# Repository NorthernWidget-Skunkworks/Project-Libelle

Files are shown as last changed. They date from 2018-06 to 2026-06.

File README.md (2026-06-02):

# Project-Libelle



*Libelle* is a spectrally-resolving shortwave pyranometer that measures solar irradiance across six spectral bands from UV-B through short-wave infrared (~280–1700 nm). The name is German for both "dragonfly" — an organism with up to 30 types of photoreceptors spanning UV to near-IR — and "spirit level," a nod to the onboard accelerometer used to correct measurements for sensor tilt.

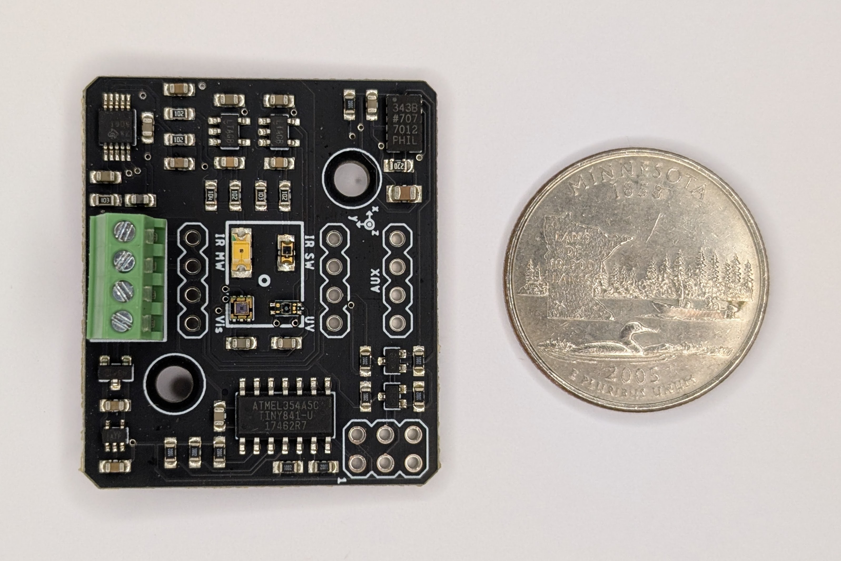
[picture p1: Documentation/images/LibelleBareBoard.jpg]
Libelle bare board next to a US quarter for scale


## Measurements

| Channel | Sensor | Approx. range |
|---|---|---|
| UV-B | VEML6075 | ~280–315 nm |
| UV-A | VEML6075 | ~315–400 nm |
| Visible (ALS) | VEML6030 | ~400–700 nm |
| White (broadband) | VEML6030 | ~300–700 nm |
| Near-IR (short) | VEMD1060X01 | ~700–1100 nm |
| Near-IR (mid) | SD003-151-001 | ~1000–1700 nm |
| Temperature | NTC thermistor | — |
| Tilt (roll + pitch) | ADXL343 | — |

Spectral response curves for each channel are in [`Analysis/SpectrumResponsePlots/`](Analysis/SpectrumResponsePlots/).

## Hardware

The board integrates its sub-sensors through an ATtiny841, which aggregates their readings and presents a single I²C slave interface to the host. The host never addresses the sub-sensors directly.

**Key ICs:** VEML6075 (UV), VEML6030 (visible/lux), VEMD1060X01 + SD003-151-001 (NIR photodiodes), ADS1115 (16-bit ADC), ADXL343 (accelerometer), ATtiny841 (I²C bridge), TPS79733 (3.3 V LDO)

### Net radiation

Two Libelle modules can share a single I²C bus simultaneously — one facing skyward (UP) and one facing down (DOWN) — to compute net shortwave radiation (↓ − ↑). The I²C address is set by solder jumper JP1:

| Orientation | Address |
|---|---|
| Up (default, JP1 open) | `0x40` |
| Down (JP1 bridged) | `0x41` |

## Electrical

- **Supply:** 3.3–5.5 V (onboard 3.3 V LDO, max input 5.5 V; I²C lines are level-shifted to match host supply)
- **Interface:** I²C (slave)
- **Connectors:** 4-pin screw terminal (J1) and 4-pin headers (J2–J4); ISP header for ATtiny firmware updates (ISP1)
- **JP1:** module I²C address select (open → `0x40`; bridged → `0x41`)
- **JP2:** ADXL343 accelerometer I²C address select (open → `0x1D`; bridged → `0x53`); for advanced use only — firmware assumes `0x1D`

### External connector pinout

| Pin | Function |
|-----|---|
| VIN | Supply (3.3–5.5 V) |
| GND | Ground |
| SDA | I²C data |
| SCL | I²C clock |

### Interrupt / auxiliary pins

| Pin | Function |
|-----|---|
| D0 | Lux interrupt (active low) |
| D1 | ADC interrupt (active low) |
| D7 | Address select (pull low → `0x41`) |

## Software

Install the [Libelle Arduino library](https://github.com/NorthernWidget-Skunkworks/Libelle_Library) from the Arduino Library Manager or by cloning the repository.

### Quick start

```cpp
#include <Libelle.h>

Libelle pyroUp(UP);

void setup() {
    Serial.begin(38400);
    pyroUp.begin();
    Serial.println(pyroUp.getHeader());
}

void loop() {
    Serial.println(pyroUp.getString());
    delay(1000);
}
```

For a net radiation setup with two modules:

```cpp
Libelle pyroUp(UP);
Libelle pyroDown(DOWN);
```

### Key API methods

| Method | Returns | Description |
|---|---|---|
| `begin()` | `bool` | Initialize; returns `false` if bridge or accelerometer unreachable |
| `getHeader()` | `String` | Comma-separated column names with units |
| `getString()` | `String` | Comma-separated measurement values |
| `getUVA()` | `long` | UV-A raw counts |
| `getUVB()` | `long` | UV-B raw counts |
| `getLux()` | `float` | Illuminance (lux) |
| `getIR_Short()` | `float` | NIR ~700–1100 nm, TIA output voltage (V) |
| `getIR_Mid()` | `float` | NIR ~1000–1700 nm, TIA output voltage (V) |
| `getTemp()` | `float` | Housing temperature (°C) |
| `getRoll()` | `float` | Roll angle (°) |
| `getPitch()` | `float` | Pitch angle (°) |

`getIR_Short()` and `getIR_Mid()` return transimpedance amplifier output voltage, not W/m². Converting to irradiance requires calibration against a reference pyranometer; see the [library documentation](https://github.com/NorthernWidget-Skunkworks/Libelle_Library) for details.

## Register map and firmware internals

The Libelle firmware runs on an ATtiny841 bridge, which exposes an I2C slave register map to the host logger. Default I2C addresses: `0x40` (UP orientation), `0x41` (DOWN orientation). The onboard ADXL343 accelerometer is read directly by the master on the same I2C bus (not bridged through the ATtiny).

Two layouts exist: the **current firmware** (deployed) and the **proposed** layout under [NW-Device-Specification](https://github.com/NorthernWidget/NW-Device-Specification) Schema 1.

### Current register map (deployed firmware)

26-byte array. Status ready flag is bit 7.

```
0x00        CTRL/Status   bit 7=ready; bit 2=auto-range disable;
                          bit 3=manual auto-range trigger; bits 1:0=update rate
0x01        —             unused
0x02–0x05   UVA           int32, compensated VEML6075 counts, little-endian
0x06        —             gap (always 0x00) ← ⚠ BUG: see below
0x07–0x0A   UVB           int32, compensated VEML6075 counts, little-endian
0x0B–0x0C   ALS           uint16, raw VEML6030 counts (visible)
0x0D–0x0E   White         uint16, raw VEML6030 counts
0x0F        —             gap
0x10–0x11   Lux mult      uint16, auto-range gain×integration scaler
0x12        —             gap
0x13–0x14   IR_Mid        uint16, raw ADS1115 counts (×1.25e-4 → V)
0x15–0x16   IR_Short      uint16, raw ADS1115 counts (×1.25e-4 → V)
0x17–0x18   Therm         uint16, raw ADS1115 counts (Steinhart-Hart → °C)
```

### ⚠ Known bug: UVB reads 256× too large

The firmware writes UVB starting at register `0x07`. The library reads UVB starting at `UVB_ADR = 0x06`. This off-by-one causes the library to assemble the UVB int32 as:

```
Byte 0 (LSB): Reg[0x06] = 0x00  ← always zero (gap byte)
Byte 1:       Reg[0x07] = UVB true byte 0
Byte 2:       Reg[0x08] = UVB true byte 1
Byte 3 (MSB): Reg[0x09] = UVB true byte 2  ← true byte 3 (Reg[0x0A]) dropped
```

Result: `getUVB()` returns approximately `true_UVB × 256`. All historical UVB data collected with this firmware and library combination is affected by this systematic error. See [issue #TBD](https://github.com/NorthernWidget/Project-Libelle/issues) for tracking.

### Proposed register map (NW-Device-Specification Schema 1)

Two 32-byte pages. The UVB register mismatch is corrected in this layout.

**Page 0 (0x00–0x1F) — Identity (EEPROM)**

```
Block 0 (0x00–0x07)   Core identity
  0x00        0x01                          Schema (NW-Device-Specification v1)
  0x01–0x07   'L','i','b','e','l','l','e'   Device name (7 bytes, exact fit)

Block 1 (0x08–0x0F)   Version
  0x08        HW major
  0x09        HW minor
  0x0A        FW patch          (NW combined-repo convention)
  0x0B–0x0D   0x00,0x00,0x00    Unused (combined repo)
  0x0E–0x0F   0x00,0x00         Reserved

Block 2 (0x10–0x17)   Serial number
  0x10–0x11   0x4C,0x01         Board type ('L'=0x4C, revision index 1)
  0x12–0x13   [manufacture]     Group ID
  0x14–0x15   [manufacture]     Unique ID
  0x16–0x17   0x00,0x00         FirmwareID (legacy, reserved)

Block 3 (0x18–0x1F)   Integrity + administration
  0x18–0x1C   0x00 ×5           Reserved
  0x1D        0x00              Magic byte (reserved; purpose TBD)
  0x1E        [computed]        CRC-8 of bytes 0x00–0x1D
  0x1F        0x4C or 0x0C      I2C address (0x4C=UP, 0x0C=DOWN; writable)
```

**Page 1 (0x20–0x3F) — Sensor data (SRAM)**

```
Block 0 (0x20–0x27)   VEML6030 — visible light
  0x20        Status       bit 0=ready, bit 1=VEML6075 fault,
                           bit 2=VEML6030 fault, bit 3=ADS1115 fault,
                           bit 7=pan-fault
  0x21        Extended faults (reserved, 0x00)
  0x22–0x23   ALS          uint16, raw VEML6030 counts, little-endian
  0x24–0x25   White        uint16, raw VEML6030 counts, little-endian
  0x26–0x27   Lux mult     uint16, auto-range scaler (ALS × mult × 0.0036 → lux)

Block 1 (0x28–0x2F)   VEML6075 — UV
  0x28–0x2B   UVA          int32, compensated counts, little-endian
  0x2C–0x2F   UVB          int32, compensated counts, little-endian

Block 2 (0x30–0x37)   ADS1115 — IR + temperature
  0x30–0x31   IR Short     uint16, raw ADC counts (×1.25e-4 → V)
  0x32–0x33   IR Mid       uint16, raw ADC counts (×1.25e-4 → V)
  0x34–0x35   Temperature  uint16, raw ADC counts (Steinhart-Hart → °C in library)
  0x36–0x37   Reserved

Block 3 (0x38–0x3F)   ADXL343 — accelerometer (hardware v2 only; see below)
  0x38–0x39   Accel X   int16, little-endian
  0x3A–0x3B   Accel Y   int16, little-endian
  0x3C–0x3D   Accel Z   int16, little-endian
  0x3E–0x3F   Reserved
```

No Page 2. Calibration constants (Steinhart-Hart coefficients, UV cross-talk compensation) are currently hardcoded in the library. If per-unit calibration is added, Page 2 is the natural home. Accelerometer calibration offsets, if needed, would also go in Page 2 following the pattern of the Apis sensor.

**Accelerometer (ADXL343):** In the current hardware (v1), the ADXL343 is wired to the master's I2C bus and read directly by the library at address `0x1D` (UP) or `0x53` (DOWN) — it is not bridged through the ATtiny. This requires the logger to manage two I2C addresses. In hardware v2, the ADXL343 will move to the ATtiny's software I2C bus so all data is accessible through a single address; Block 3 of Page 1 is reserved for this. See [issue #19](https://github.com/NorthernWidget-Skunkworks/Project-Libelle/issues/19).

### Migration notes for Schema 1 update

1. **Status bit:** Current firmware uses bit 7 of `Reg[0x00]` as the ready flag; Schema 1 places the status byte at 0x20 with bit 0 as the ready flag. Both the register address and the bit position must change together.
2. **UVB register offset:** Correct firmware to write UVB at `0x28` (Page 1, Block 1) — eliminates the ×256 error.
3. **Auto-range:** `bit 2` and `bit 3` of CTRL need equivalent representation in Schema 1 status/config byte.

## Mechanical

CNC-millable mounting hardware designs are available on [Easel (Inventables)](https://www.inventables.com/):

- [Pipe mount](https://easel.inventables.com/projects/cAirZefIUws53oghGYYopw) — accepts 1.25"–3.25" ID pipe with 1/4" U-bolts (common US sizes: 1.25", 1.5", 1.75", 2")
- [Drilling jig](https://easel.inventables.com/projects/s-fOn9DWTmkeizO0vO8MGw) — for the Libelle enclosure box

| Pipe mount | Enclosure circle cut |
|---|---|
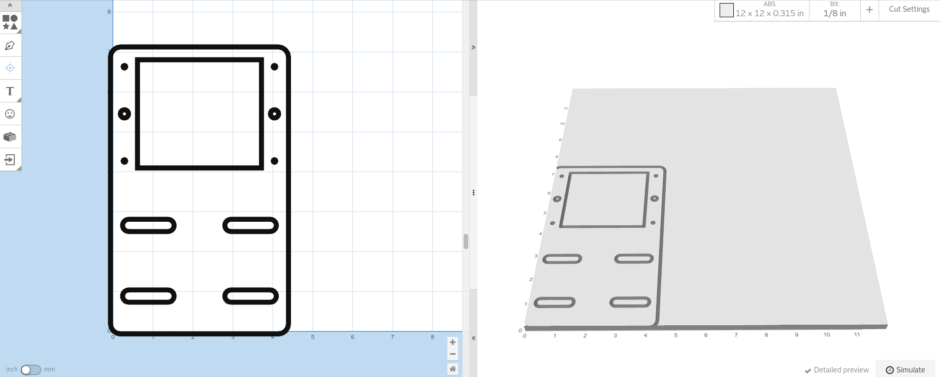
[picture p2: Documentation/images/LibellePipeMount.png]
Pipe mount CNC design
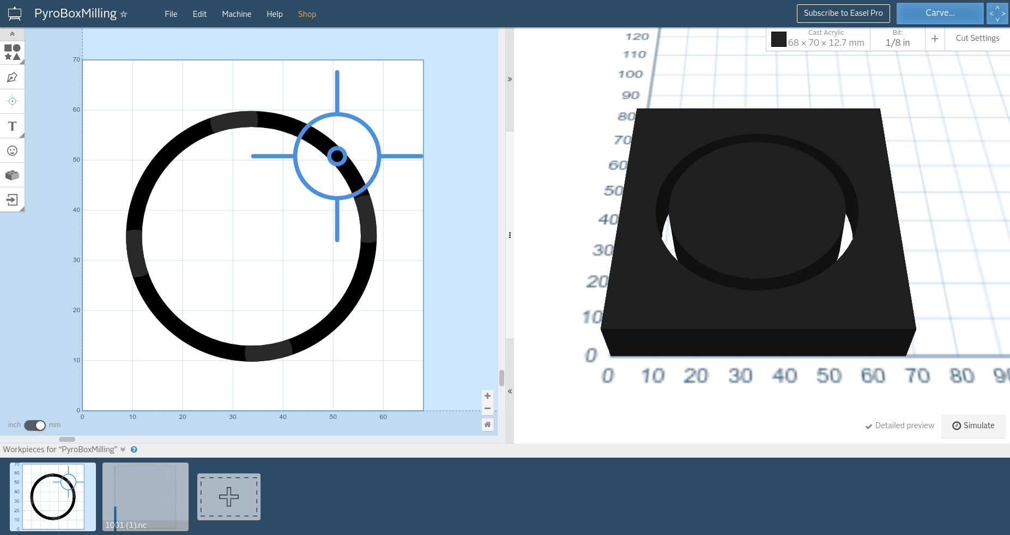
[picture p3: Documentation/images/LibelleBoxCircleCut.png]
Enclosure circle cut CNC design
|  |  |

SolidWorks source files and STLs are in [`Mechanical/`](Mechanical/).

## Related projects

- [Project-Liasis](https://github.com/NorthernWidget-Skunkworks/Project-Liasis) — companion longwave (thermal IR) pyrgeometer
- [Liasis Library](https://github.com/NorthernWidget-Skunkworks/Liasis_Library) — Arduino library for the Liasis pyrgeometer

## NW-Device-Specification — Schema 1, Page 0

Implements [NW-Device-Specification](https://github.com/NorthernWidget/NW-Device-Specification) Schema 1. The 32-byte identity block (Page 0) is stored at the top of EEPROM:

```
Block 0:  Schema=0x01, Name='L','i','b','e','l','l','e'
Block 1:  HW major=[mfr], HW minor=[mfr], FW patch=[mfr], 0x00,0x00,0x00, Reserved
Block 2:  Board type=0x4C01 ('L'=0x4C, rev 1), Group ID=[mfr], Unique ID=[mfr], FirmwareID=0x0000
Block 3:  Reserved, Magic=0x00, CRC=[computed], I2C address=0x4C (UP) / 0x0C (DOWN)
```

Legacy deployed units carry board types `0x2300`/`0x2301` (formerly Dyson SW, Monarch SW).

## License

Hardware:  <a rel="license" href="http://creativecommons.org/licenses/by-sa/4.0/">Creative Commons Attribution-ShareAlike 4.0 International</a>

Firmware: [GNU General Public License v3](LICENSE_for_code)

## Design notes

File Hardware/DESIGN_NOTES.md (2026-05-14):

# Hardware Design Notes

## Power supply: LDO vs. buck converter

The TPS79733 (ultra-low-Iq 3.3 V LDO, <1 µA Iq) was chosen over a synchronous buck converter
(TPS62172, 500 mA, 2.5–7 V input). Two simulation files documenting this exploration were
removed from the repo after this note was written (recoverable from git history):

- `Simulations/slvm434a/` — PSpice transient startup simulation of TPS62172 (OrCAD binary)
- `Simulations/PowerFilter.asc` — LTSpice AC sweep of LC + RC output filter topologies
  (L swept 100 µH–2 mH, R = 27 Ω, C = 44 µF), evaluating whether buck switching noise
  could be adequately filtered for the analog signal chain

The LDO was chosen for two reasons:

1. **Analog noise sensitivity.** The two LTC2054 TIA op-amps driving the IR photodiodes are
   extremely sensitive to supply noise. Buck-converter switching ripple (and its harmonics)
   would couple directly into the transimpedance measurement. The PowerFilter simulations
   represent the investigation into whether filtering could solve this; the complexity and
   board area of a multi-stage LC filter were apparently not worth it compared to simply
   using an LDO.

2. **Low load current.** Total board current is well below 50 mA (ATtiny841 + VEML6075 +
   VEML6030 + ADS1115 + ADXL343 + 2× LTC2054). The efficiency loss of an LDO at this
   current level (≤85 mW dissipation from a 5 V supply) is negligible for a solar radiation
   sensor, which is not battery-constrained.

Even with the clean LDO supply, R3 (27 Ω) in the SmallBoard design forms an RC filter
between the digital 3V3 rail and the ADXL343's VS analog supply pin, providing an extra
layer of decoupling for the accelerometer's analog domain.

## Transimpedance amplifier for NIR photodiodes

`Simulations/PhotodiodeAmp.asc` and `Simulations/PhotodiodeAmp_Photoelectric.asc` simulate
the LTC2054 TIA circuit used for the IR photodiode channels (VEMD1060X01 and SD003-151-001).

- `PhotodiodeAmp.asc` — DC sweep of photodiode current (–1.59 µA), 1 MΩ feedback, 2 µF
  feedback capacitor, 100-run Monte Carlo for component tolerance analysis.
- `PhotodiodeAmp_Photoelectric.asc` — Full photodiode model (Cj = 10 pF, Rsh = 2 GΩ,
  Rs = 1 µΩ), transient analysis, Monte Carlo. R1 = 1 kΩ, R2 = 1 MΩ, R3 = 2 kΩ,
  C1 = 0.15 µF, C2 = 0.01 µF.

The 1 MΩ feedback resistor sets the transimpedance gain; output is a voltage proportional
to photodiode current, reported as volts (not W/m²). Irradiance calibration requires
comparison against a reference pyranometer.

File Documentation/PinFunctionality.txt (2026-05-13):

Pin Functionality Libelle Short-Wave

Pin		Function
D0		Lux Int, Active Low
D1		Adc Int, Active Low
D7		Slave Address Select 
D3		Software SCL
D2		Software SDA

Function Explanation:

Lux Int:
Lux sensor (VEML6030) can be configured to output an interrupt for certian situations, this pin is native high (pull up), and it pulled low by the Lux sensor if an interrupt is triggered. Interrupt trigger must be configured by user.

Adc Int:				
ADC (ADS1115) can be configured to output an interrupt for certian situations, this pin is native high (pull up), and it pulled low by the ADC sensor if an interrupt is triggered (generally used to indicate a finished conversion). Interrupt trigger must be configured by user.

Slave Address Select:
This pin is used to select I2C device (if the device is the "top" or "bottom" device). This pin must be pulled up internally, and is natively floating (can be pulled up internally). This pin is an input, when the solder jumper on the board (J1) is jumped, this pin is pulled low, indicating the alternate device address should be used.

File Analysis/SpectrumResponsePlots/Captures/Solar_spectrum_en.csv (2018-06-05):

x | Curve1
204.85 | 0.1295
216.07 | 0.18429
225.9 | 0.23908
234.31 | 0.29387
242.73 | 0.34866
249.75 | 0.40574
255.36 | 0.46053
262.38 | 0.51761
269.39 | 0.5724
276.41 | 0.62948
282.02 | 0.68655
287.63 | 0.74135
294.65 | 0.79842
300.26 | 0.85322
307.27 | 0.91029
312.89 | 0.96737
319.9 | 1.02216
325.51 | 1.07924
332.53 | 1.13403
339.54 | 1.19111
346.56 | 1.2459
353.57 | 1.30298
360.59 | 1.35777
369.01 | 1.41256
377.43 | 1.46964
387.25 | 1.52443
398.47 | 1.5952
402.68 | 1.62716
412.5 | 1.64998
426.53 | 1.7002
439.16 | 1.73215
458.8 | 1.77779
486.87 | 1.80973
519.14 | 1.80741
531.76 | 1.79597
558.42 | 1.76169
582.27 | 1.71828
603.32 | 1.67258
622.96 | 1.62689
660.85 | 1.53095
679.09 | 1.48297
712.76 | 1.3916
731 | 1.34363
747.84 | 1.29565
766.08 | 1.24768
784.32 | 1.19971
798.38 | 1.16441
815.62 | 1.11836
836.39 | 1.07159
852.74 | 1.02698
870.86 | 0.99171
888.14 | 0.9507
910.59 | 0.90728
933.04 | 0.86159
955.49 | 0.81818
979.34 | 0.77705
996.18 | 0.74735
1020.03 | 0.70622
1045.29 | 0.66737
1071.94 | 0.62852
1097.2 | 0.59195
1111.23 | 0.57367
1137.89 | 0.53939
1167.35 | 0.5051
1196.82 | 0.47538
1226.28 | 0.44566
1255.75 | 0.41594
1288.02 | 0.39079
1318.88 | 0.36335
1351.15 | 0.34048
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

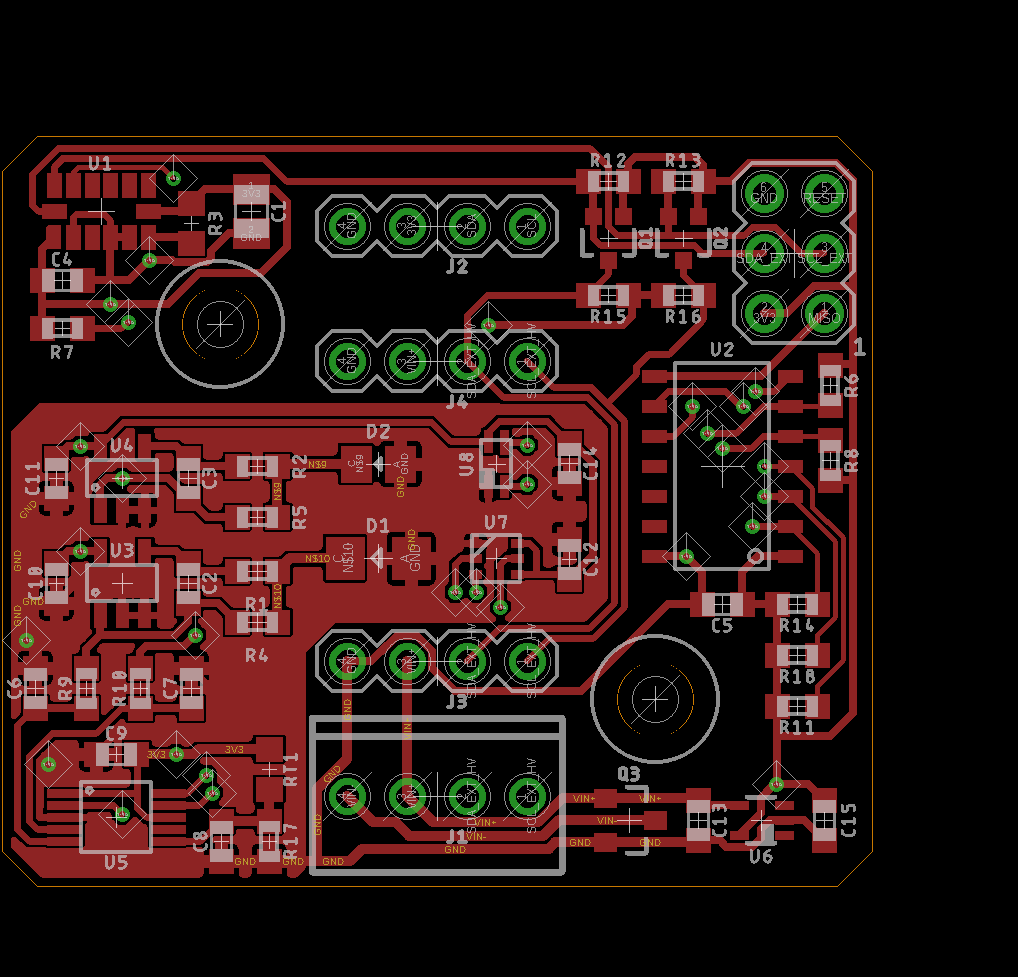
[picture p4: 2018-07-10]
Hardware/Libelle_RefDesignators.png

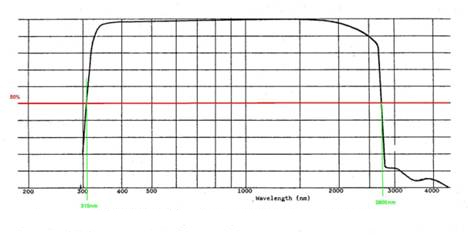
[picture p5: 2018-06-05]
Analysis/SpectrumResponsePlots/Captures/Spectral_Range_KippZonen.jpg

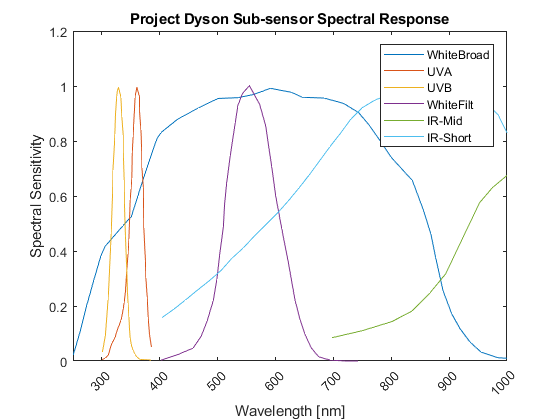
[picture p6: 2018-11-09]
Analysis/SpectrumResponsePlots/PAR_Spectrum.png

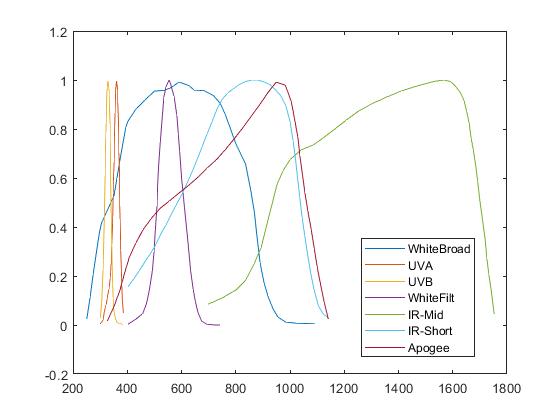
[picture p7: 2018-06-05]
Analysis/SpectrumResponsePlots/Spectrum.jpg

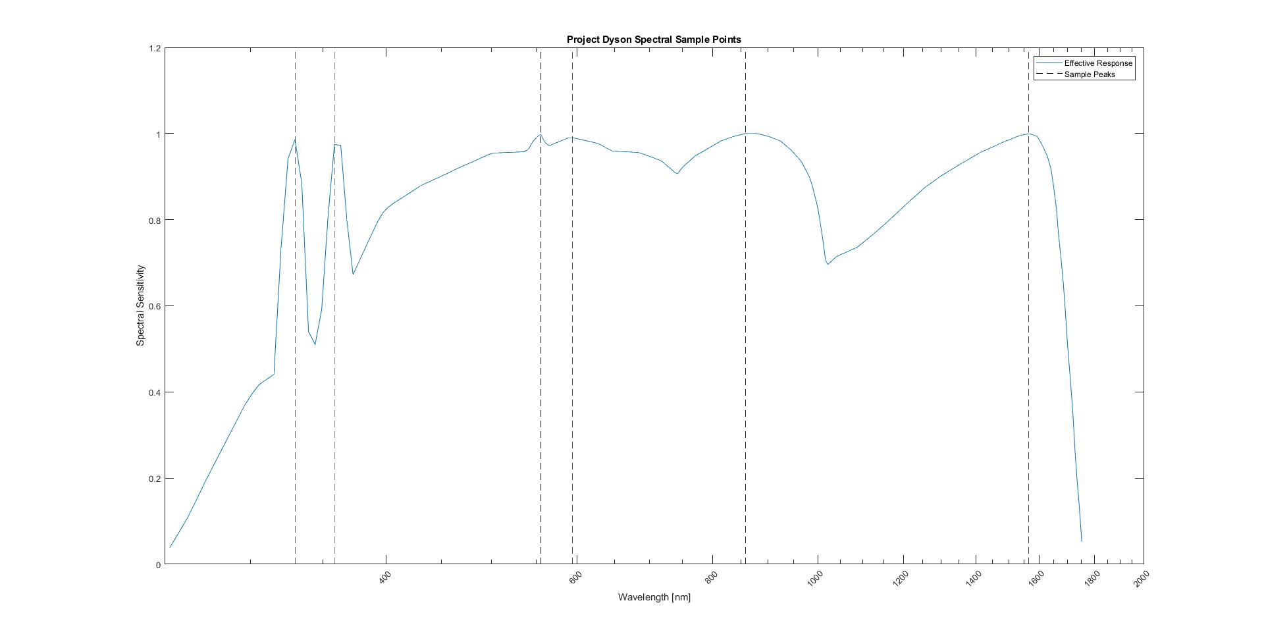
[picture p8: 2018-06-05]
Analysis/SpectrumResponsePlots/Libelle_SamplePeaks.jpg

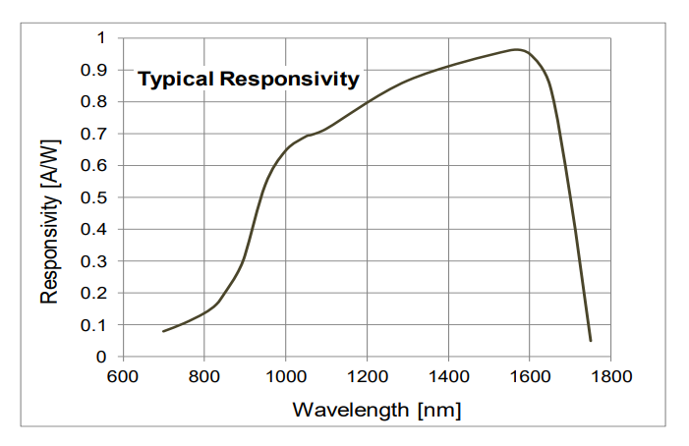
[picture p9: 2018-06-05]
Analysis/SpectrumResponsePlots/Captures/IR_MidWave_Response.png

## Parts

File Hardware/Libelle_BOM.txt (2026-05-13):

Partlist exported from C:/Users/You/Documents/Project-Libelle/Hardware/ShortWaveModule_SmallBoard.sch at 7/9/2018 9:44 AM

Qty Value                   Device                  Package              Parts                                         Description                                                                          DIGIKEY                DISP    MF                  MPN                PROD_ID     VALUE   VALUE_PART
2                           MOUNTING_HOLE4_NP       4_40                 H1, H2                                        Genaric Mechanical Mounting Hole                                                                                                                                                         
2   0.15uF                  C-EU0.15UFC0603         C0603                C2, C3                                        CAPACITOR, European symbol                                                           732-7990-1-ND                  Wurth               885012206072                                     
8   0.1uF                   C-EU0.1UFC0603          C0603                C4, C5, C8, C9, C10, C11, C12, C14            CAPACITOR, European symbol                                                           490-6051-1-ND                  Murata              GCM188R71E104KA57D                               
1   100k                    R-EU_P100KR0603         R0603                R4                                            RESISTOR, European symbol                                                            P100KDBCT-ND                   Panasonic           ERA-3AEB104V                           100k      
10  10k                     R-EU_10KR0603           R0603                R6, R7, R8, R11, R12, R13, R14, R15, R16, R18 RESISTOR, European symbol                                                            P10.0KHCT-ND                   Panasonic           ERJ-3EKF1002V                          10k       
1   10k                     R-EU_P10KR0603          R0603                R17                                           RESISTOR, European symbol                                                            P10KDBCT-ND                    Panasonic           ERA-3AEB103V                           10k       
1   10k                     R-EU_P10KR0603          R0603                R5                                            RESISTOR, European symbol                                                            P10KDBCT-ND                    Panasonic           ERA-3AEB103V                           10k       
1   10k                     THERMISTOR10K           R0603                RT1                                           Thermistor                                                                           490-16279-1-ND                 Murata              NCU18XH103F60RB                                  
1   10uF                    C-EU10UFC0805           C0805                C1                                            CAPACITOR, European symbol                                                           490-6473-6-ND                  Murata              GRM21BR61C106KE15K                               
4   1k                      R-EU_P1KR0603           R0603                R1, R2, R9, R10                               RESISTOR, European symbol                                                            P1.0KDBCT-ND                   Panasonic           ERA-3AEB102V                           1k        
4   1uF                     C-EU1UFC0603            C0603                C6, C7, C13, C15                              CAPACITOR, European symbol                                                           1276-6524-1-ND                 Samsung             1276-6524-1-ND                                   
1   27R                     R-EU_27R0603            R0603                R3                                            RESISTOR, European symbol                                                            311-27.0HRCT-ND                Yageo               RC0603FR-0727RL                        27        
2   2N7002                  MOSFET-NCH-2N7002PW     SOT323               Q1, Q2                                        N-channel MOSFETs                                                                    2N7002W-FDICT-ND               Diodes Incorporated 2N7002W-7-F        TRANS-11151 2N7002            
1   ADS1115                 ADS1115                 VSSOP_10             U5                                            ADS1115 - Sigma Delta ADC                                                            296-38849-1-ND                 TI                  ADS1115IDGSR                                     
1   ADXL343                 ADXL343                 LGA-14               U1                                            ADXL343 - Digital Accelerometer(I2C/SPI)                                             ADXL343BCCZ-ND                 Analog Devices      ADXL343BCCZ                                      
1   ATTINY441/841841        ATTINY441/841841        SOIC_14              U2                                            ATTINY441, ATTINY841 8 bit MCU, 4/8k flash, 256/512B SRAM                            ATTINY841-SSU-ND               Atmel               ATTINY841-SSU                                    
1   AVRISP-6                AVRISP-6                AVRISP               ISP1                                          AVR ISP HEADER                                                                                                                                                                           
3   CONN_42.54              CONN_42.54              1X04                 J2, J3, J4                                    Genaric 4 pin connector                                                                                                                                                                  
1   CONN_42.54_SCREW        CONN_42.54_SCREW        1X04_SCREW           J1                                            Genaric 4 pin connector                                                              ED10563-ND                     On Shore            OSTVN04A150                                      
1   DMG3404                 MOSFET-NCH-DMG3404L     SOT23-3              Q3                                            N-channel MOSFETs                                                                    DMG3404L-7DICT-ND              Diodes Incorporated DMG3404L-7                     DMG3404           
2   JUMPER-SMT_2_NO_SILK    JUMPER-SMT_2_NO_SILK    SMT-JUMPER_2_NO_SILK JP1, JP2                                      Normally open jumper                                                                                                                                                                     
2   LTC2054                 LTC2054                 SOT23-5              U3, U4                                        LTC2054 -Single Micropower Zero Drift Op-Amp                                         LTC2054HS5#TRMPBFCT-ND LTC2054 LT                  LTC2054HS5#TRMPBF                                
1   PHOTODIODESD003-151-001 PHOTODIODESD003-151-001 D1206                D1                                            Photodiode                                                                           SD003-151-001CT-ND             Luna Opto           SD003-151-001                                    
1   PHOTODIODEVEMD1060      PHOTODIODEVEMD1060      D0805                D2                                            Photodiode                                                                           VEMD1060X01CT-ND               Vishay              VEMD1060X01                                      
1   TPS79733                TPS79733                DCK_R-PDSO-G5        U6                                            TPS797xx, Ultra low power linear voltage regulator, fixed voltages of 1.8v, 3v, 3.3v 296-11990-1-ND                 TI                  TPS79733DCKR                                     
1   VEML6030                VEML6030                VEML6030             U7                                            VEML6030 - Ambient Light Sensor with I2C Interface                                   VEML6030-GS15CT-ND             Vishay              VEML6030-GS15                                    
1   VEML6075                VEML6075                VEML6075             U8                                            VEML6075 - UVA and UVB Light Sensor with I2C Interface                               VEML6075CT-ND                  Vishay              VEML6075

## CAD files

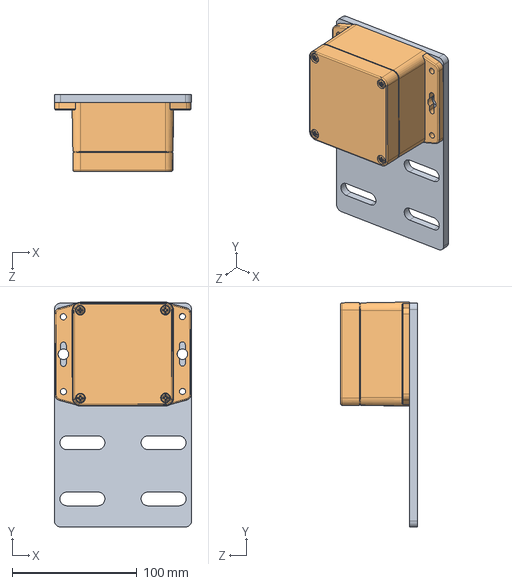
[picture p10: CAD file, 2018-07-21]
Mechanical/PipeMount.SLDASM
110.0 x 180.3 x 61.5 mm
PipeMount
W_-31F1

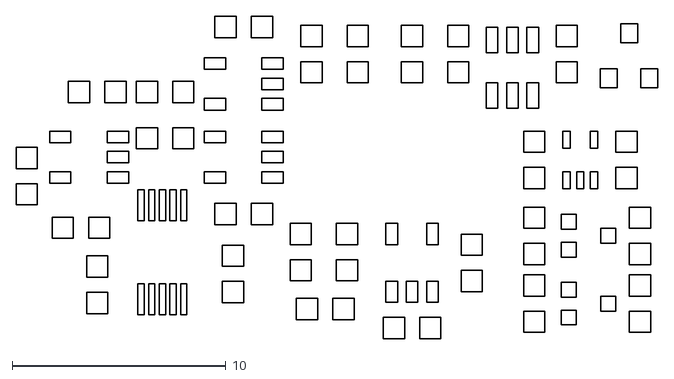
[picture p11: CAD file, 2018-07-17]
Hardware/Stencil.dxf
30.0 x 15.1

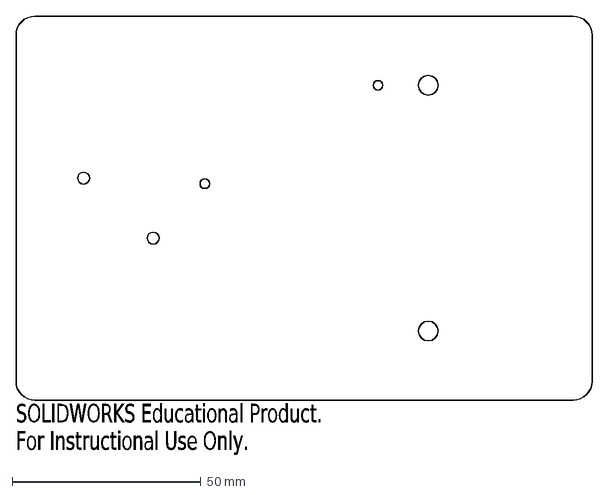
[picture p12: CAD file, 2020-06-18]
Mechanical/CNC/TestWith_KippZonen/PyroTestingPlate.DXF
SOLIDWORKS Educational Product.
For Instructional Use Only.

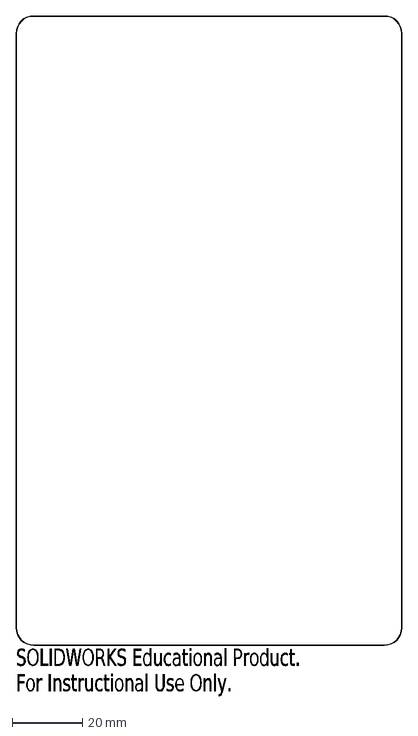
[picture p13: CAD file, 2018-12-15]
Mechanical/PipeMount_Outline.DXF
SOLIDWORKS Educational Product.
For Instructional Use Only.

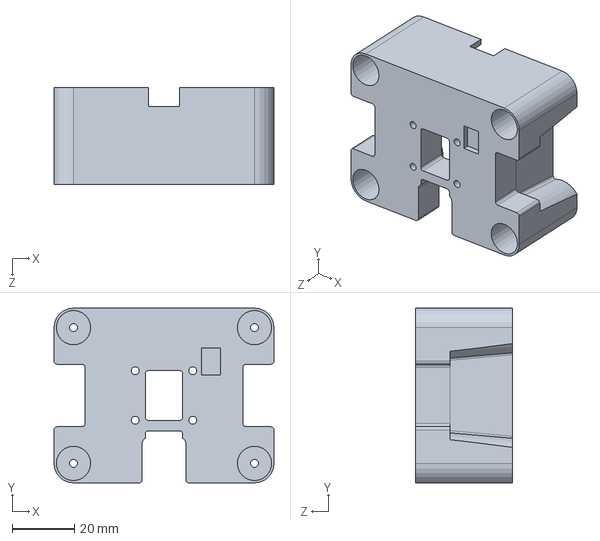
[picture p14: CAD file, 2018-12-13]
Mechanical/BoardCaseMount_DesicantHolders.SLDPRT
70.5 x 56.0 x 31.0 mm

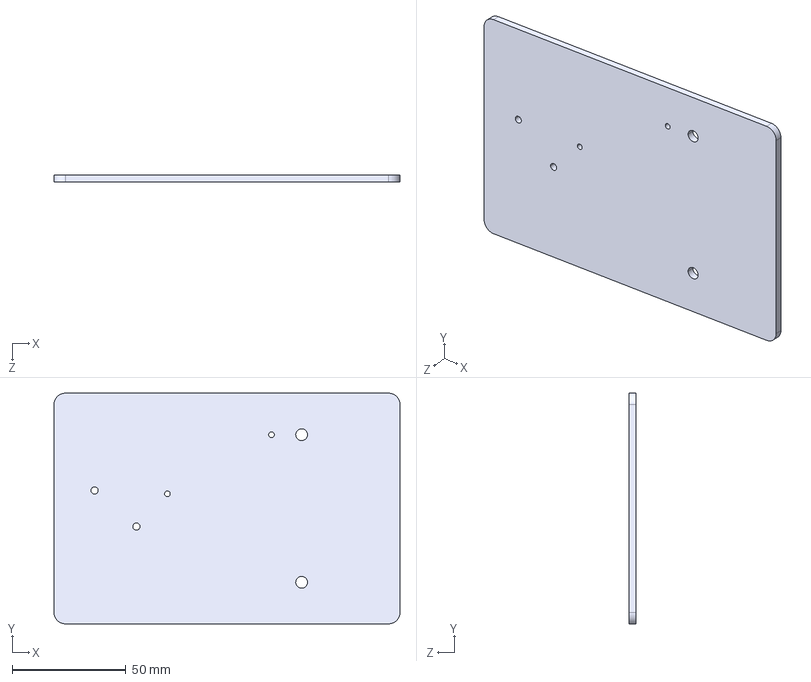
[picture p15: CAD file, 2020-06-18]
Mechanical/CNC/TestWith_KippZonen/PyroTestingBoard.STEP
152.4 x 101.6 x 3.17 mm

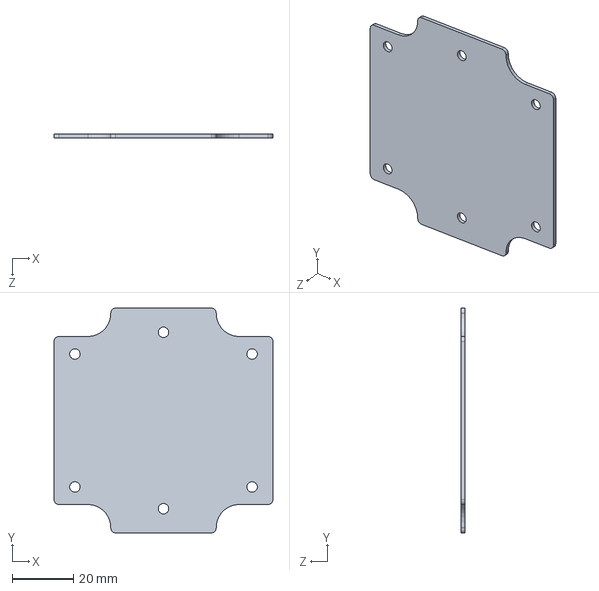
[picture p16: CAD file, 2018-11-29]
Mechanical/WP-31_InternalMountPlate.SLDPRT
71.7 x 73.6 x 1.20 mm

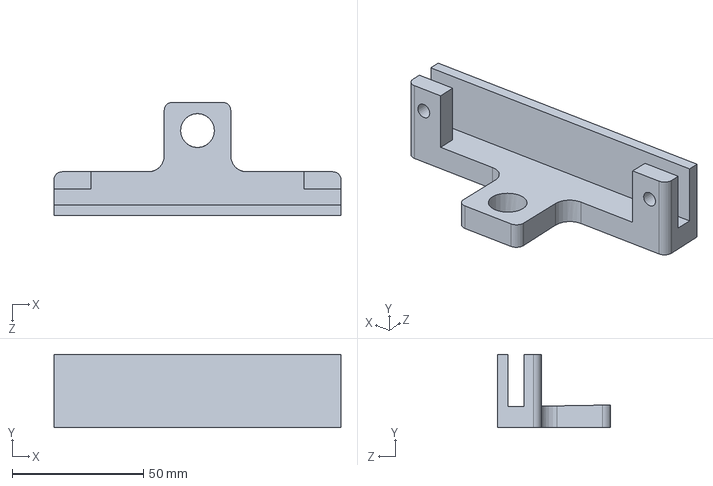
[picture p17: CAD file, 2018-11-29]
Mechanical/DrillGuide.SLDPRT
109.4 x 28.0 x 43.1 mm

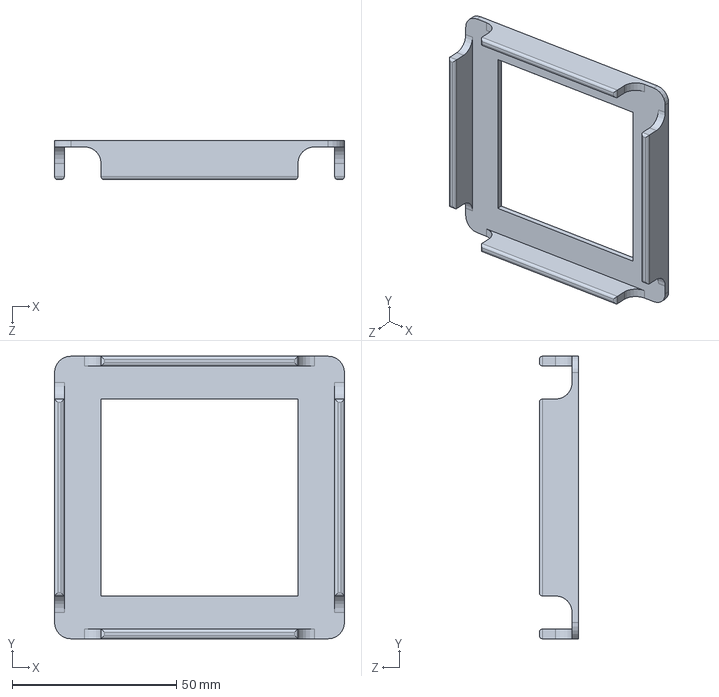
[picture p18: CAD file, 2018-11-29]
Mechanical/DiffuserGuide_TOP.SLDPRT
88.4 x 86.1 x 12.0 mm

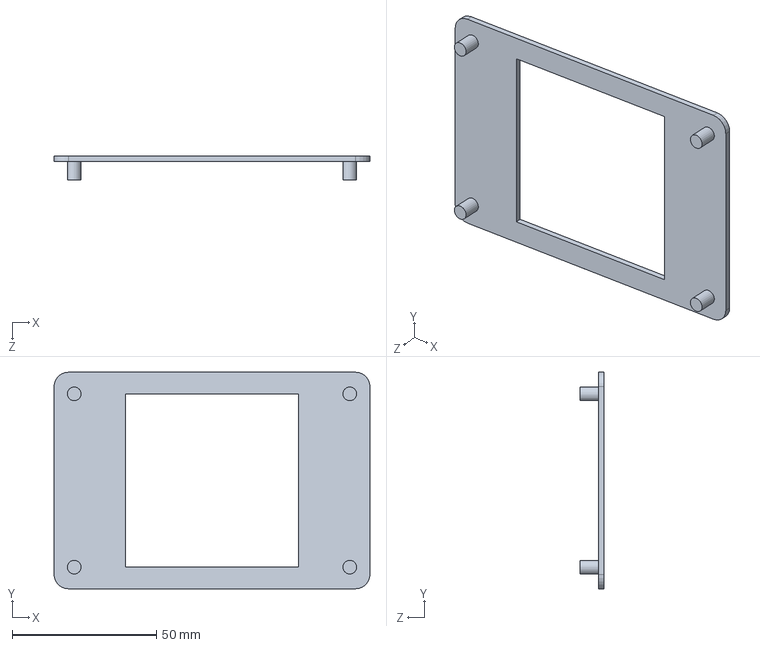
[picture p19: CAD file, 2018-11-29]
Mechanical/DiffuserGuide_BOTTOM.SLDPRT
109.4 x 75.0 x 8.35 mm

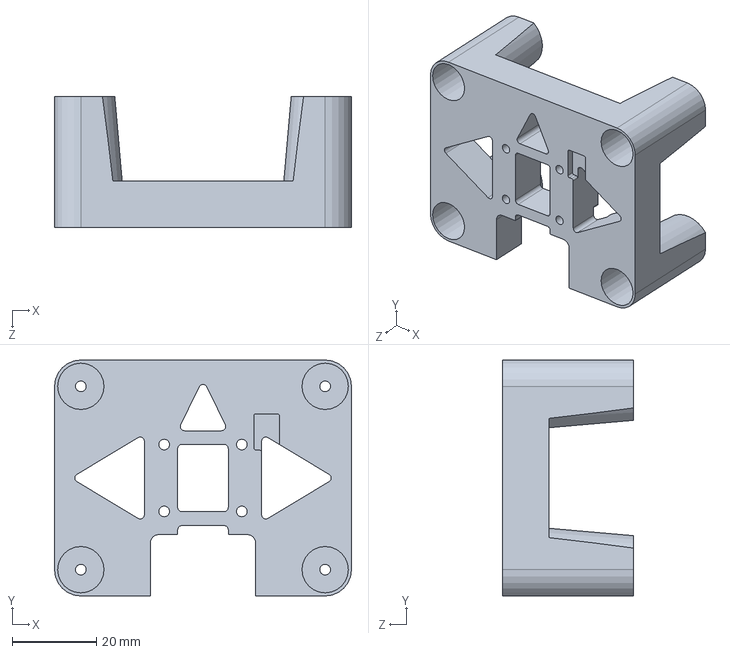
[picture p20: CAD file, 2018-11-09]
Mechanical/BoardCaseMount.SLDPRT
70.5 x 56.0 x 31.0 mm

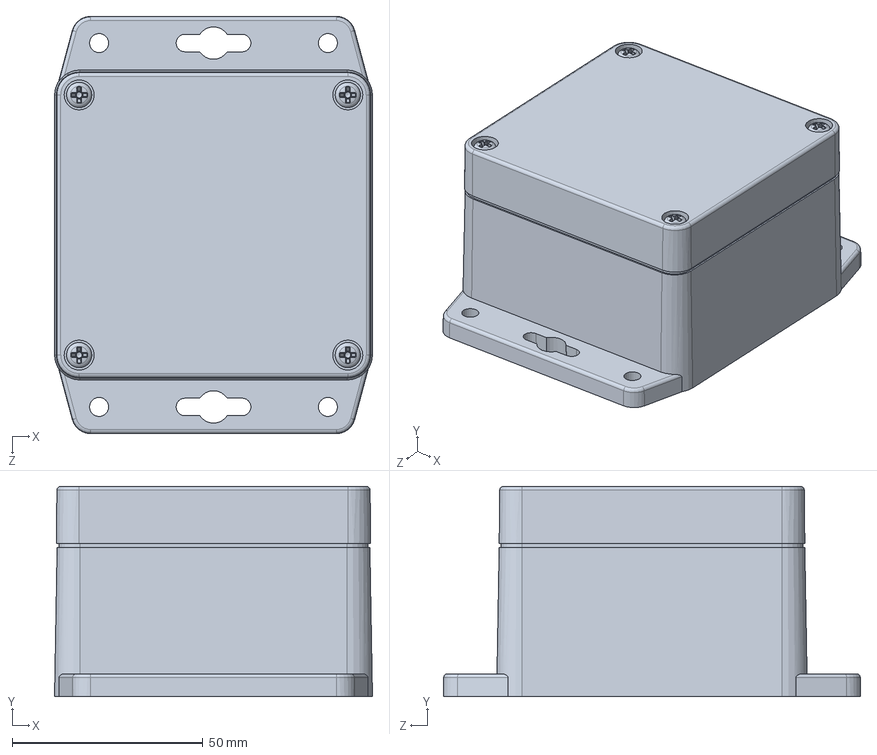
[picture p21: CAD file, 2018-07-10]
Mechanical/W_-31F1.SLDPRT
83.4 x 55.1 x 109.4 mm

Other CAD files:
Mechanical/BoardCaseMount.STL
Mechanical/BoardCaseMount_DesicantHolders.STL
Mechanical/CNC/TestWith_KippZonen/PyroTestingBoard.SLDPRT
Mechanical/CNC/TestWith_KippZonen/PyroTestingBoard.STL
Mechanical/DiffuserGuide_BOTTOM.STL
Mechanical/DiffuserGuide_TOP.STL
Mechanical/DrillGuide.STL
Mechanical/PipeMount.DXF
Mechanical/PipeMount.SLDPRT

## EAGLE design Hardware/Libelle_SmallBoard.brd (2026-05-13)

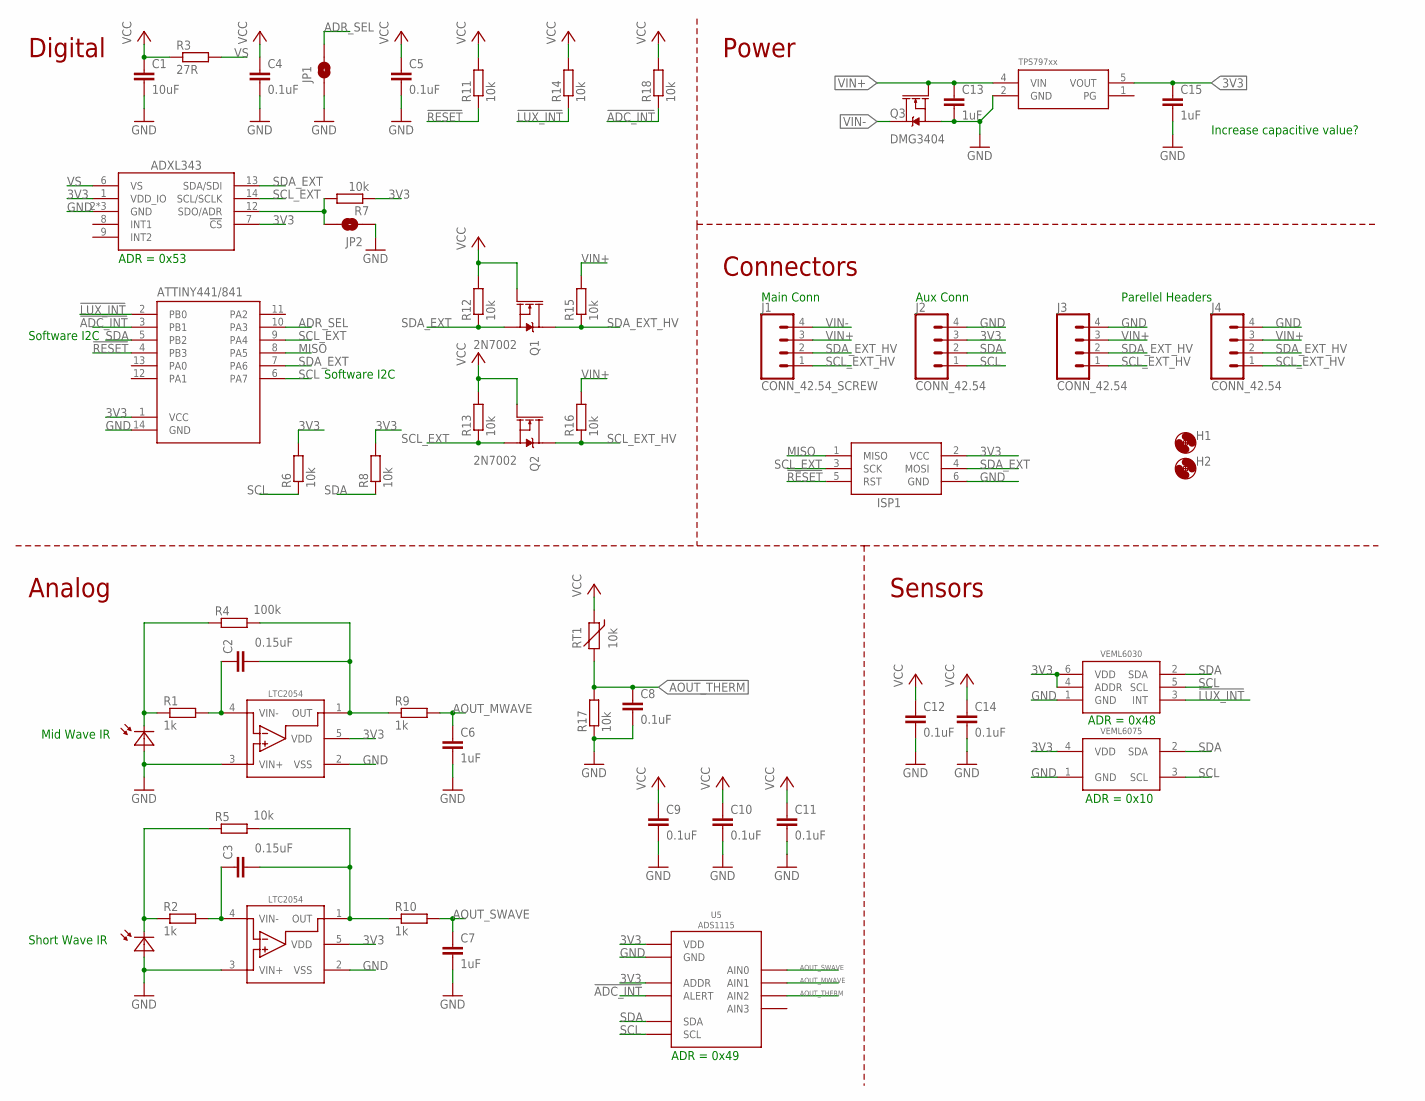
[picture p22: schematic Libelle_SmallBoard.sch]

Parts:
C1: 10uF; C0805
C2, C3: 0.15uF; C0603
C4, C5, C8, C9, C10, C11, C12, C14: 0.1uF; C0603
C6, C7, C13, C15: 1uF; C0603
D1: PHOTODIODESD003-151-001; D1206
D2: PHOTODIODEVEMD1060; D0805
H1, H2: MOUNTING_HOLE4_NP; 4_40
ISP1: AVRISP-6; AVRISP
J1: CONN_42.54_SCREW; 1X04_SCREW
J2, J3, J4: CONN_42.54; 1X04
JP1, JP2: JUMPER-SMT_2_NO_SILK; SMT-JUMPER_2_NO_SILK
Q1, Q2: 2N7002; SOT323
Q3: DMG3404; SOT23-3
R1, R2, R9, R10: 1k; R0603
R3: 27R; R0603
R4: 100k; R0603
R5, R6, R7, R8, R11, R12, R13, R14, R15, R16, R18: 10k; R0603
R17: 10k; R0603; MPN ERA-3AEB103V; DIGIKEY P10KDBCT-ND
RT1: 10k; R0603
U1: ADXL343; LGA-14
U2: ATTINY441/841841; SOIC_14
U3, U4: LTC2054; SOT23-5
U5: ADS1115; VSSOP_10
U6: TPS79733; DCK_R-PDSO-G5
U7: VEML6030
U8: VEML6075

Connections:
3V3: C1.1, C4.1, C5.1, C9.1, C10.1, C11.1, C12.1, C14.1, C15.1, ISP1.2 (VCC), J2.3, Q1.1 (G), Q2.1 (G), R3.1, R6.2, R7.1, R8.2, R11.2, R12.2, R13.2, R14.2, R18.2, RT1.1 (2), U1.1 (VDD_IO), U1.7 (!CS), U2.1 (VCC), U3.5 (VDD), U4.5 (VDD), U5.1 (ADDR), U5.8 (VDD), U6.5 (VOUT), U7.4 (ADDR), U7.6 (VDD), U8.4 (VDD)
!ADC_INT: R18.1, U2.3 (PB1), U5.2 (ALERT)
!LUX_INT: R14.1, U2.2 (PB0), U7.3 (INT)
!RESET: ISP1.5 (RST), R11.1, U2.4 (PB3)
ADR_SEL: JP1.2, U2.10 (PA3)
AOUT_MWAVE: C6.1, R9.2, U5.5 (AIN1)
AOUT_SWAVE: C7.1, R10.2, U5.4 (AIN0)
AOUT_THERM: C8.1, R17.2, RT1.2 (1), U5.6 (AIN2)
GND: C1.2, C4.2, C5.2, C6.2, C7.2, C8.2, C9.2, C10.2, C11.2, C12.2, C13.2, C14.2, C15.2, D1.A, D2.A, ISP1.6 (GND), J2.4, J3.4, J4.4, JP1.1, JP2.1, Q3.2 (S), R17.1, U1.2 (GND), U1.4 (GND), U1.5 (GND), U2.14 (GND), U3.2 (VSS), U3.3 (VIN+), U4.2 (VSS), U4.3 (VIN+), U5.3 (GND), U6.2 (GND), U7.1 (GND), U8.1 (GND)
MISO: ISP1.1 (MISO), U2.8 (PA5)
unnamed: JP2.2, R7.2, U1.12 (SDO/ADR)
unnamed: C3.1, R2.2, U4.4 (VIN-)
unnamed: D2.C, R2.1, R5.1
unnamed: D1.C, R1.1, R4.1
unnamed: C2.1, R1.2, U3.4 (VIN-)
unnamed: C2.2, R4.2, R9.1, U3.1 (OUT)
unnamed: C3.2, R5.2, R10.1, U4.1 (OUT)
SCL: J2.1, R6.1, U2.6 (PA7), U5.10 (SCL), U7.5 (SCL), U8.3 (SCL)
SCL_EXT: ISP1.3 (SCK), Q2.2 (S), R13.1, U1.14 (SCL/SCLK), U2.9 (PA4)
SCL_EXT_HV: J1.1, J3.1, J4.1, Q2.3 (D), R16.1
SDA: J2.2, R8.1, U2.5 (PB2), U5.9 (SDA), U7.2 (SDA), U8.2 (SDA)
SDA_EXT: ISP1.4 (MOSI), Q1.2 (S), R12.1, U1.13 (SDA/SDI), U2.7 (PA6)
SDA_EXT_HV: J1.2, J3.2, J4.2, Q1.3 (D), R15.1
VIN+: C13.1, J1.3, J3.3, J4.3, Q3.1 (G), R15.2, R16.2, U6.4 (VIN)
VIN-: J1.4, Q3.3 (D)
VS: R3.2, U1.6 (VS)

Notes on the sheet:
Software I2C
ADR = 0x48
ADR = 0x10
ADR = 0x49
Increase capacitive value?
Digital
Sensors
Power
Analog
Short Wave IR
Mid Wave IR
Connectors
Main Conn
Aux Conn
Parellel Headers
ADR = 0x53

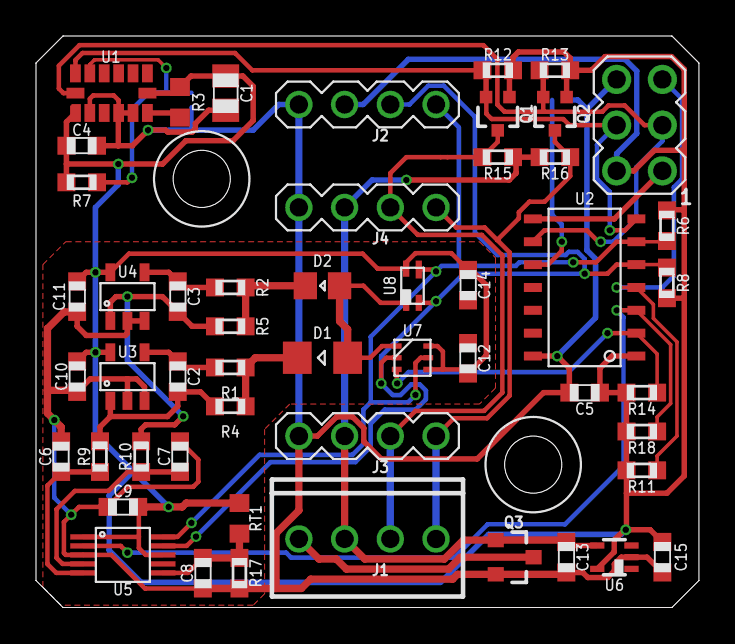
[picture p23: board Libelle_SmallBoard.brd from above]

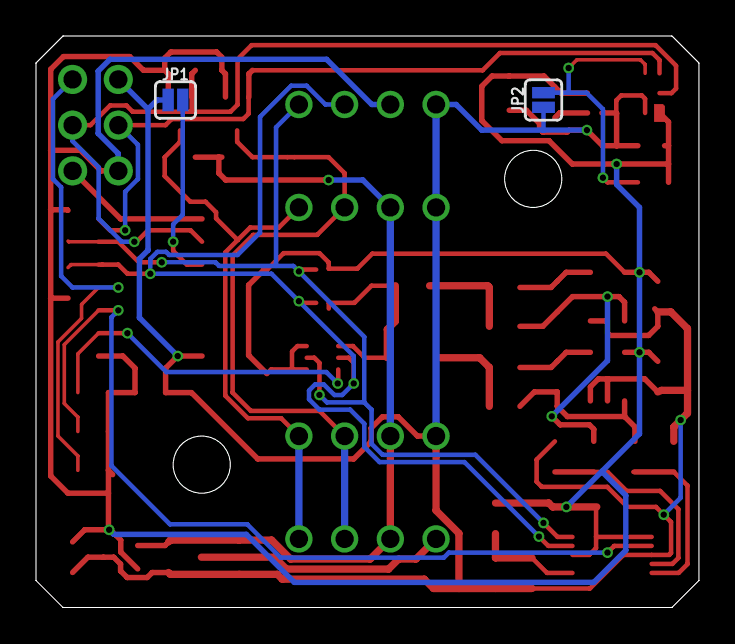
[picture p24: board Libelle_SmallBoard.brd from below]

Board: 2 copper layers, 36.8 x 31.8 mm, 56 parts (2 on the bottom side), 26 nets.

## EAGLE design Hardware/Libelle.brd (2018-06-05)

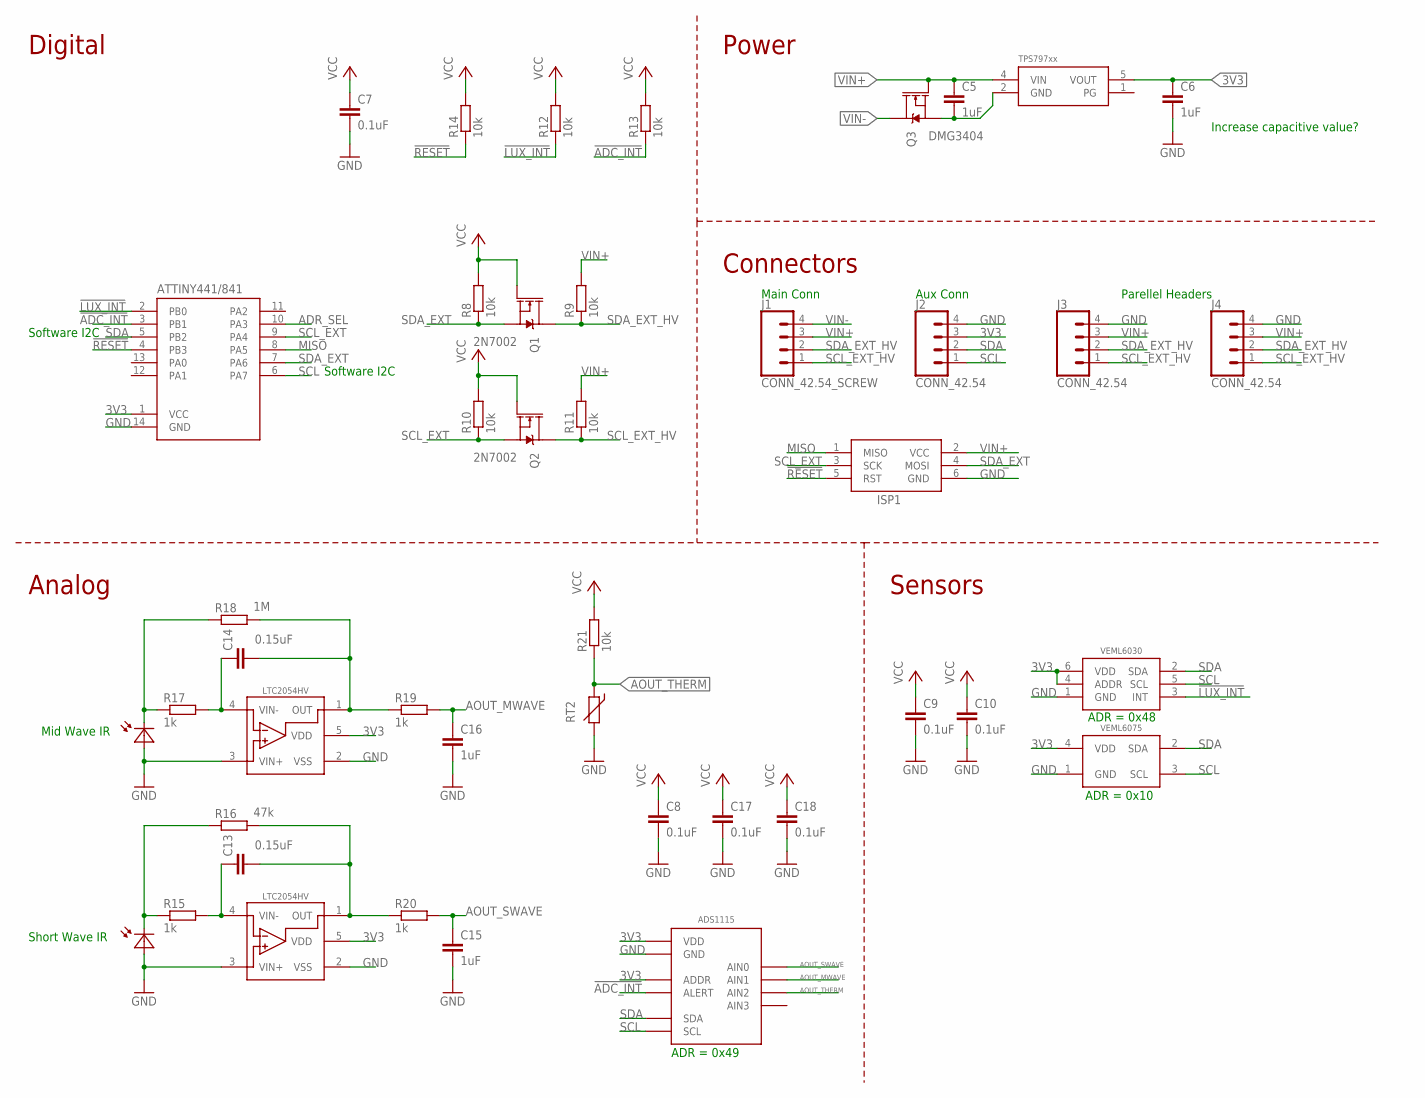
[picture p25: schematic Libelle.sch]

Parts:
ADS1115: ADS1115; VSSOP_10
C5, C6, C15, C16: 1uF; C0603
C7, C8, C9, C10, C17, C18: 0.1uF; C0603
C13, C14: 0.15uF; C0603
ISP1: AVRISP-6; AVRISP
J1: CONN_42.54_SCREW; 1X04_SCREW
J2, J3, J4: CONN_42.54; 1X04
Q1, Q2: 2N7002; SOT323
Q3: DMG3404; SOT23-3
R8, R9, R10, R11, R12, R13, R14, R21: 10k; R0603
R15, R17, R19, R20: 1k; R0603
R16: 47k; R0603
R18: 1M; R0603
RT2: THERMISTOR10K; R0603
U$1: ATTINY441/841841; SOIC_14
U$2: VEML6030
U$3: VEML6075
U$5: TPS79733; DCK_R-PDSO-G5
U$9: PHOTODIODEMTD5010W; TO-18
U$10: PHOTODIODESD003-151-001; D1206
U$11, U$12: LTC2054HV; SOT23-5

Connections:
3V3: ADS1115.1 (ADDR), ADS1115.8 (VDD), C6.1, C7.1, C8.1, C9.1, C10.1, C17.1, C18.1, J2.3, Q1.1 (G), Q2.1 (G), R8.2, R10.2, R12.2, R13.2, R14.2, R21.2, U$1.1 (VCC), U$2.4 (ADDR), U$2.6 (VDD), U$3.4 (VDD), U$5.5 (VOUT), U$11.5 (VDD), U$12.5 (VDD)
!ADC_INT: ADS1115.2 (ALERT), R13.1, U$1.3 (PB1)
!LUX_INT: R12.1, U$1.2 (PB0), U$2.3 (INT)
!RESET: ISP1.5 (RST), R14.1, U$1.4 (PB3)
ADR_SEL: U$1.10 (PA3)
AOUT_MWAVE: ADS1115.5 (AIN1), C14.2, R18.2, R19.1, U$11.1 (OUT)
AOUT_SWAVE: ADS1115.4 (AIN0), C13.2, R16.2, R20.1, U$12.1 (OUT)
AOUT_THERM: ADS1115.6 (AIN2), R21.1, RT2.1
GND: ADS1115.3 (GND), C6.2, C7.2, C8.2, C9.2, C10.2, C15.2, C16.2, C17.2, C18.2, ISP1.6 (GND), J2.4, J3.4, J4.4, RT2.2, U$1.14 (GND), U$2.1 (GND), U$3.1 (GND), U$9.ANODE (A), U$10.A, U$11.2 (VSS), U$11.3 (VIN+), U$12.2 (VSS), U$12.3 (VIN+)
MISO: ISP1.1 (MISO), U$1.8 (PA5)
unnamed: C5.2, Q3.2 (S), U$5.2 (GND)
unnamed: C13.1, R15.2, U$12.4 (VIN-)
unnamed: R15.1, R16.1, U$9.CATHODE (C)
unnamed: R17.1, R18.1, U$10.C
unnamed: C14.1, R17.2, U$11.4 (VIN-)
unnamed: C16.1, R19.2
unnamed: C15.1, R20.2
SCL: ADS1115.10 (SCL), J2.1, U$1.6 (PA7), U$2.5 (SCL), U$3.3 (SCL)
SCL_EXT: ISP1.3 (SCK), Q2.2 (S), R10.1, U$1.9 (PA4)
SCL_EXT_HV: J1.1, J3.1, J4.1, Q2.3 (D), R11.1
SDA: ADS1115.9 (SDA), J2.2, U$1.5 (PB2), U$2.2 (SDA), U$3.2 (SDA)
SDA_EXT: ISP1.4 (MOSI), Q1.2 (S), R8.1, U$1.7 (PA6)
SDA_EXT_HV: J1.2, J3.2, J4.2, Q1.3 (D), R9.1
VIN+: C5.1, ISP1.2 (VCC), J1.3, J3.3, J4.3, Q3.1 (G), R9.2, R11.2, U$5.4 (VIN)
VIN-: J1.4, Q3.3 (D)

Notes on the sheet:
Software I2C
ADR = 0x48
ADR = 0x10
ADR = 0x49
Increase capacitive value?
Digital
Sensors
Power
Analog
Short Wave IR
Mid Wave IR
Connectors
Main Conn
Aux Conn
Parellel Headers

Board: 2 copper layers, 44 parts (0 on the bottom side), 24 nets, no tracks yet.

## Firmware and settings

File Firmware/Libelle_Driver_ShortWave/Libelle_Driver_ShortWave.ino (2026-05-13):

//Libelle_Driver_ShortWave.ino
//v0.0.0
#include "SlowSoftI2CMaster.h"
#include "WireS.h"
// #include <EEPROM.h> //DEBUG!
//Commands

#define CTRL 0x00  //Define location of onboard control/confiuration register

#define CONF_CMD 0x00
#define ALS_CMD 0x04
#define WHITE_CMD 0x05

#define UVA_CMD 0x07
#define UVB_CMD 0x09
#define COMP1_CMD 0x0A
#define COMP2_CMD 0x0B

#define ADC_CONF 0x01
#define ADC_CONV 0x00
#define ADC0 0x4200
#define ADC1 0x5200
#define ADC2 0x6200
#define ADC3 0x7200

#define VIS_ADR 0x48
#define UV_ADR 0x10
#define ADC_ADR 0x49

#define READ 0x01
#define WRITE 0x00

#define BUF_LENGTH 64 //Length of I2C Buffer, verify with documentation 

#define LOW_LIM_VIS 10000  //Lower limit to the auto ranging of the VEML6030
#define HIGH_LIM_VIS 55000 //Upper limit to the auto ranging of the VEML6030

#define ADR_SEL_PIN 7 //Digital pin 7 is used to test which device address should be used
// #define ADR_ALT 0x41 //Alternative device address

//Global values for gain and int time of visable light sensor
uint8_t Gain = 0;
unsigned int IntTime = 0;
uint8_t GainValsVis[4] = {0b10, 0b11, 0b00, 0b01}; //Gain values for visible sensor
uint8_t GainsVis[4] = {1, 2, 8, 16}; //Gain multipliers for visable sensor 
uint8_t IntTimeValsVis[6] = {0b1100, 0b1000, 0b0000, 0b0001, 0b0010, 0b0011}; //Integration time values for visible sensor

//Compensation constants
float a = 1.92;
float b = 0.55;
float c = 2.46;
float d = 0.63;

volatile uint8_t ADR = 0x40; //Use arbitraty address, change using generall call??
const uint8_t ADR_Alt = 0x41; //Alternative device address  //WARNING! When a #define is used instead, problems are caused

uint8_t Config = 0; //Global config value

uint8_t Reg[26] = {0}; //Initialize registers
bool StartSample = true; //Flag used to start a new converstion, make a conversion on startup
// const unsigned int UpdateRate = 5; //Rate of update
const unsigned int UpdateRate[] = {5, 10, 60, 300}; //FIX with better numbers! 

SlowSoftI2CMaster si = SlowSoftI2CMaster(PIN_B2, PIN_A7, true);  //Initialize software I2C

volatile bool StopFlag = false; //Used to indicate a stop condition 
volatile uint8_t RegID = 0; //Used to denote which register will be read from
volatile bool RepeatedStart = false; //Used to show if the start was repeated or not

void setup() {
  Serial.begin(115200); //DEBUG!
  Serial.println("begin"); //DEBUG!
  Reg[CTRL] = 0x00; //Set Config to POR value
  pinMode(ADR_SEL_PIN, INPUT_PULLUP);
  pinMode(10, OUTPUT); //DEBUG!
  pinMode(9, OUTPUT); //DEBUG!
  digitalWrite(10, HIGH); //DEBUG!
  digitalWrite(9, LOW); //DEBUG!
  if(!digitalRead(ADR_SEL_PIN)) ADR = ADR_Alt; //If solder jumper is bridged, use alternate address //DEBUG!
  Wire.begin(ADR);  //Begin slave I2C
  // EEPROM.write(0, ADR);
  InitVEML(0x48); //Init Vis (VEML6030)
  InitVEML(0x10); //Init UV (VEML6075)
  InitADC(); //Init ADC (ADS1115)

  //Setup I2C slave
	Wire.onAddrReceive(addressEvent); // register event
	Wire.onRequest(requestEvent);     // register event
	Wire.onReceive(receiveEvent);
	Wire.onStop(stopEvent);

  si.i2c_init(); //Begin I2C master

  // AutoRange_Vis(); //Auto range for given light conditions
	digitalWrite(9, HIGH); //DEBUG!
	digitalWrite(10, LOW); //DEBUG!
}

void loop() {
	// static unsigned int Count = 0; //Counter to determine update rate
	// uint8_t Ctrl = Reg[CTRL]; //Store local value to improve efficiency
	uint8_t UpdateRateBits = Reg[CTRL] & 0x03; 
	static unsigned long Timeout = millis() % (UpdateRate[3]*1000); //Take mod with longest update rate 

	// digitalWrite(10, HIGH); //DEBUG!
	if(StartSample == true) {

		// Config = Reg[CTRL]; //Update local register val
		//Read new values in
		if(BitRead(Reg[CTRL], 2) == 0) {  //Only auto range if configured in Ctrl register 
			AutoRange_Vis();  //Run auto range
			delay(800); //Wait for new sample
		}
		// digitalWrite(9, HIGH); //DEBUG!
		Reg[CTRL] = Reg[CTRL] &= 0x7F; //Clear ready flag only while new vals being written
		SplitAndLoad(0x0B, GetALS()); //Load ALS value
		SplitAndLoad(0x0D, GetWhite()); //Load white value
		SplitAndLoad(0x02, long(GetUV(0))); //Load UVA
		SplitAndLoad(0x07, long(GetUV(1))); //Load UVB
		SplitAndLoad(0x10, GetLuxGain()); //Load lux multiplier 
		SplitAndLoad(0x13, GetADC(0));
		SplitAndLoad(0x15, GetADC(1));
		SplitAndLoad(0x17, GetADC(2));

		Reg[CTRL] = Reg[CTRL] |= 0x80; //Set ready flag
		digitalWrite(9, LOW); //DEBUG!
		StartSample = false; //Clear flag when new values updated  
	}

	//Make sure there is not a protnetial logic problem when changing update rate!!!!!!
	if(millis() % (UpdateRate[3]*1000) - Timeout > UpdateRate[UpdateRateBits]*1000) {  
		StartSample = true; //Set flag if number of updates have rolled over 
		Timeout = millis() % (UpdateRate[3]*1000); //Restart timer
		// digitalWrite(10, LOW); //DEBUG!
	}

	if(BitRead(Reg[CTRL], 3) == 1) {  //If manual autorange is commanded
		AutoRange_Vis(); //Call autorange
		delay(800); //Wait for new data
		Reg[CTRL] &= 0xF7; //Clear auto range bit to inform user autorange is complete
	}

	// if(Reg[CTRL] != Config) {
	// 	Config = Reg[CTRL]; //Update local register 
	// 	Timeout = millis() % (UpdateRate[3]*1000); //Reset counter if control register changes
	// }
	delay(100);
}

uint8_t InitVEML(uint8_t Adr) 
{
	uint8_t CMD = 0; 
	if(Adr == 0x48) CMD = 0x13;  //DEBUG! Replace w/0x23 or 0x13 
	else CMD = 0;
    si.i2c_start((Adr << 1) | WRITE);
    si.i2c_write(0x00);
    si.i2c_write(0x00);
    si.i2c_write(CMD);
    si.i2c_stop(); 

    return 0; //Fix dummy
    //Setup gain and integration values manually! 
}

uint8_t InitADC() 
{
	//Setup ADC system 
	WriteWord_LE(ADC_ADR, ADC_CONF, ADC0); //Set to single shot mode with 
}

unsigned int GetADC(unsigned int Num)
{
	unsigned int ADC_Config = ADC0 | (Num << 12); //Use to select which ADC to get data from
	WriteWord_LE(ADC_ADR, ADC_CONF, ADC_Config); //Setup registers
	delay(300);  //Wait for next sample to be read
	return ReadWord_LE(ADC_ADR, ADC_CONV); //Read from register
}

float GetUV(uint8_t Sel) //Select A or B using Sel value (0 or 1) 
{
	float Comp1 = ReadWord(UV_ADR, COMP1_CMD);
	float Comp2 = ReadWord(UV_ADR, COMP2_CMD);

	float UV = 0;
	float UV_Comp = 0;
	if(Sel == 0) {
		UV = ReadWord(UV_ADR, UVA_CMD);
		UV_Comp = UV - a*Comp1 - b*Comp2;
		// Serial.println(UV);
	}

	if(Sel == 1) {
		UV = ReadWord(UV_ADR, UVB_CMD);
		UV_Comp = UV - c*Comp1 - d*Comp2;
	}

	return UV_Comp;
}

unsigned int GetALS() 
{
	return ReadWord(VIS_ADR, ALS_CMD);
}

unsigned int GetWhite() 
{
	return ReadWord(VIS_ADR, WHITE_CMD);
}

unsigned int GetLuxGain() 
{	//Add non-linear correction! 
	float GainTemp = float(Gain); //Hardcode max range for gain and int time 
	float IntTimeTemp = float(IntTime);  
	float Resolution = (1.8432/IntTimeTemp)/GainTemp;
	// unsigned int Resolution = (512/(IntTime/25.0))/(Gain/0.125);
	Serial.println(int(Resolution/0.0036)); //DEBUG!
	return int(Resolution/0.0036); //Return Lux scaler
}


uint8_t AutoRange_Vis() 
{	
	// WriteWord(VIS_ADR, CONF_CMD, (GainValsVis[0] << 11) | (IntTimeValsVis[0] << 6)); //Write min gain vals
	WriteWord(VIS_ADR, CONF_CMD, 0x1300); //DEBUG! Replace w/ 0x1300
	delay(800); //Wait for new sample
	unsigned int Val = GetALS();
	Serial.print("Val = "); Serial.println(Val); //DEBUG!
	// Serial.println(Val); //DEBUG!
	if(Val > HIGH_LIM_VIS) {
		Gain = GainsVis[0];  //Set global values
		IntTime = pow(2, 0); 
	}

	bool InRange = false; //Flag to test for range
	unsigned int ValTest = 0;
	uint8_t GainTemp = 0;  //Index of desired gain
	uint8_t IntTimeTemp = 0; //Index of desired integration time
	//DEBUG!!!!!!
	// while(!InRange && IntTimeTemp < 6) {
	// 	ValTest = (Val*int(GainsVis[GainTemp])*(1 << int(IntTimeTemp)));
	// 	Serial.print("Val = "); Serial.println(ValTest); //DEBUG!
	// 	Serial.print("D = "); Serial.print(GainsVis[GainTemp]); Serial.print("\t"); Serial.println(IntTimeTemp);
	// 	if(ValTest < LOW_LIM_VIS) {
	// 		GainTemp++;
	// 	}
	// 	if(GainTemp > 3 && IntTimeTemp < 5) {
	// 		GainTemp = 0;
	// 		IntTimeTemp++;
	// 	}

	// 	if(GainTemp == 3 && IntTimeTemp == 5) InRange = true; //Set if max value is reached 
	// 	if(ValTest > LOW_LIM_VIS && ValTest < HIGH_LIM_VIS) InRange = true; //Found correct gain and int vals
	// }
	GainTemp = 0; //DEBUG!
	IntTimeTemp = 0;  //DEBUG!
	//DEBUG!
	// Serial.print(GainValsVis[GainTemp], BIN); Serial.print("\t"); Serial.println(IntTimeValsVis[IntTimeTemp], BIN);  //DEBUG!
	// WriteWord(VIS_ADR, CONF_CMD, (GainValsVis[GainTemp] << 11) | (IntTimeValsVis[IntTimeTemp] << 6));  //Write new gain value
	// Serial.print((GainValsVis[GainTemp] << 11) | (IntTimeValsVis[IntTimeTemp] << 6), HEX); //DEBUG!
	Gain = GainsVis[GainTemp];  //Set global values
	IntTime = pow(2, IntTimeTemp); 
}
// float GetGain(uint8_t GainBits)
// {
// 	uint8_t X0 = ReadBit(GainBits, 1);
// 	uint8_t X1 = ReadBit(GainBits, 0);
// 	Gain = pow(2, X0 - 3*X1);
// 	return Gain; 
// }

// unsigned int Gain2Bits(float GainVal)
// {
// 	for(int i = 0; i < 4; i++) {  //Use linear search to avoid float math and increase speed
// 		if(GainVals[i] == GainVal) {
// 			return (i << 11); //if entries match, return bits
// 		}
// 	}
// 	return 0x1000; //Return gain of 1/8 if not a valid gain value 
// }

// unsigned int GetIntTime()
// {
// 	Config = ReadWord(CONF_CMD); //Update global config value
// 	int X2X1 = (Config >> 6) & 0x03; 
// 	int X3 = ReadBit(Config, 8);
// 	int X4 = ReadBit(Config, 9);
// 	IntTime = 100*pow(2, X2X1)/pow(2, X3 + X4);  //Do some ugly math to go from bit pattern to value
// 	return IntTime; 
// }

// unsigned int IntTime2Bits(unsigned int Time)
// {
// 	uint8_t X2X1 = (int)(log(Time/100)/log(2));
// 	uint8_t X4X3 = (int)(((Time % 100) / 25) + 2*(Time % 50)/25);
// 	return ((X4X3 << 2) | (X2X1)) << 6; 
// }

// uint8_t SetGain(unsigned int GainVal)
// {
// 	Config = ReadWord(CONF_CMD); //Update global config value
// 	// Serial.print("Config = "); //DEBUG!
// 	// Serial.print(Config); //DEBUG! 
// 	// Serial.print(" "); //DEBUG!
// 	// Serial.println((Config & 0xE7FF) | GainVal); //DEBUG!
// 	return WriteConfig((Config & 0xE7FF) | GainVal);
// }

// uint8_t AutoRange()  //Automatically finds maximum gain and resolution values for given irradiance
// {
// 	// PowerSaveOff(); //Turn power save off for fastest reading
// 	SetIntTime(IT25); //Set to minimum integration time
// 	SetGain(GAIN_1_8); //Set to minmum gain
// 	// Serial.print("UnRanged Result ="); Serial.println(ReadWord(CONF_CMD), HEX); //DEBUG!
// 	// PowerOn();
// 	// long StartTime = millis(); //DEBUG! 
// 	// while(millis() - StartTime < 50) {  //DEBUG!
// 	// 	Serial.println(ReadWord(INT_CMD), HEX); //DEBUG!
// 	// }  //DEBUG!
// 	delay(30); //Wait for new sample
// 	float TestLux = GetLux(); //Get new lux value
// 	unsigned long HighLux = 120796;  //Start at max value
// 	unsigned int NewIntTime = 25; //Default to min value
// 	float NewGainHigh = 0.125; //Default to min value
// 	float NewGainLow = 0.25; //Default to 2nd lowest value
// 	float NewGain = 0.125; //Default to min value
// 	// Serial.print("LuxTest = "); //DEBUG!
// 	// Serial.println(TestLux); //DEBUG!
// 	//Increment through lux ranges to find desired gain range
// 	if(TestLux < 236) {  //If Lux is too small to measure at max values (<1.8432) or in minimum range, simply set to highest gain and integration time
// 		NewIntTime = 800;
// 		NewGain = 2;
// 	}
// 	else {  //If lux is not outside low range, search for a value
// 		for(int i = 0; i < 6; i++) {
// 			if(TestLux < HighLux && TestLux >= HighLux/2.0) {
// 				NewIntTime = NewIntTime * ceil(pow(2, i));
// 				break; //breakout of for loop since result is found
// 			}
// 			else HighLux = ceil(HighLux/2.0); //If not found, go to next lux range
// 		}

// 		if(TestLux < HighLux * 0.0625) NewGain = 2; //If below the lowest max for integration range, set to max gain
// 		else {  //Otherwise search for a new value 
// 			for(int g = 1; g < 3; g++) {
// 				if(TestLux < HighLux * (0.125/NewGainHigh) && TestLux >= HighLux * (0.125/NewGainLow)) {
// 					NewGain = NewGainHigh;
// 					break; //Break loop once gain is found
// 				}
// 				else {
// 					NewGainHigh = NewGainLow;
// 					NewGainLow = GetGain(GainValBits[g + 1]);
// 				}
// 			}
// 		}
// 	}

// 	// Serial.print("AutoRange Vals = "); Serial.print(NewGain); Serial.print(" "); Serial.println(NewIntTime); //DEBUG!
// 	unsigned int GainBits = Gain2Bits(NewGain); //Convert new gain value
// 	unsigned int IntBits = IntTime2Bits(NewIntTime); //Convert to new integration time
// 	// Serial.print("Bits = "); Serial.print(GainBits, HEX); Serial.print(" "); Serial.println(IntBits, HEX); //DEBUG!

// 	SetGain(GainBits);
// 	SetIntTime(IntBits);
// 	// Serial.print("AutoRanged Result ="); Serial.println(ReadWord(CONF_CMD), HEX); //DEBUG!
// }

// float GetGain()
// {
// 	Config = ReadWord(CONF_CMD); //Update global config value
// 	// Serial.println(Config); //DEBUG!
// 	int X0 = ReadBit(Config, 11);
// 	int X1 = ReadBit(Config, 12);
// 	Gain = pow(2, X0 - 3*X1);
// 	return Gain; 
// }

// unsigned int GetIntTime()
// {
// 	Config = ReadWord(CONF_CMD); //Update global config value
// 	int X2X1 = (Config >> 6) & 0x03; 
// 	int X3 = ReadBit(Config, 8);
// 	int X4 = ReadBit(Config, 9);
// 	IntTime = 100*pow(2, X2X1)/pow(2, X3 + X4);  //Do some ugly math to go from bit pattern to value
// 	return IntTime; 
// }

// float GetLux() 
// {	//Add non-linear correction! 
// 	GetGain(); //Update global values
// 	GetIntTime(); 
// 	float Resolution = (1.8432/((float)IntTime/25.0))*(0.125/Gain);
// 	// Serial.print("TEST = "); //DEBUG!
// 	// Serial.print(Resolution); //DEBUG!
// 	// Serial.print(" "); //DEBUG!
// 	// Serial.print(IntTime); //DEBUG! 
// 	// Serial.print(" "); //DEBUG!
// 	// Serial.println(Gain); //DEBUG!
// 	return GetALS()*Resolution; //Return scaled Lux mesurment
// }

// uint8_t ReadBit(unsigned int Data, uint8_t Pos)
// {
// 	return (Data >> Pos) & 0x01; 
// }

bool BitRead(uint8_t Val, uint8_t Pos) //Read the bit value at the specified position
{
	return (Val >> Pos) & 0x01;
}

uint8_t SendCommand(uint8_t Adr, uint8_t Command)
{
    si.i2c_start((Adr << 1) | WRITE);
    bool Error = si.i2c_write(Command);
    return 1; //DEBUG!
}

uint8_t WriteWord(uint8_t Adr, uint8_t Command, unsigned int Data)  //Writes value to 16 bit register
{
	si.i2c_start((Adr << 1) | WRITE);
	si.i2c_write(Command); //Write Command value
	si.i2c_write(Data & 0xFF); //Write LSB
	uint8_t Error = si.i2c_write((Data >> 8) & 0xFF); //Write MSB
	si.i2c_stop();
	return Error;  //Invert error so that it will return 0 is works
}

uint8_t WriteWord_LE(uint8_t Adr, uint8_t Command, unsigned int Data)  //Writes value to 16 bit register
{
	si.i2c_start((Adr << 1) | WRITE);
	si.i2c_write(Command); //Write Command value
	si.i2c_write((Data >> 8) & 0xFF); //Write MSB
	si.i2c_write(Data & 0xFF); //Write LSB
	si.i2c_stop();
	// return Error;  //Invert error so that it will return 0 is works
}

uint8_t WriteConfig(uint8_t Adr, uint8_t NewConfig)
{
	si.i2c_start((Adr << 1) | WRITE);
	si.i2c_write(CONF_CMD);  //Write command code to Config register
	uint8_t Error = si.i2c_write(NewConfig);
	si.i2c_stop();
	if(Error == true) {
		Config = NewConfig; //Set global config if write was sucessful 
		return 0;
	}
	else return -1; //If write failed, return failure condition
}

int ReadByte(uint8_t Adr, uint8_t Command, uint8_t Pos) //Send command value, and high/low byte to read, returns desired byte
{
	bool Error = SendCommand(Adr, Command);
	si.i2c_rep_start((Adr << 1) | READ);
	uint8_t ValLow = si.i2c_read(false);
	uint8_t ValHigh = si.i2c_read(false);
	si.i2c_stop();
	Error = true; //DEBUG!
	if(Error == true) {
		if(Pos == 0) return ValLow;
		if(Pos == 1) return ValHigh;
	}
	else return -1; //Return error if read failed

}

int ReadWord(uint8_t Adr, uint8_t Command)  //Send command value, returns entire 16 bit word
{
	bool Error = SendCommand(Adr, Command);
	Serial.print("Error = "); Serial.println(Error); //DEBUG!
	si.i2c_rep_start((Adr << 1) | READ);
	uint8_t ByteLow = si.i2c_read(false);  //Read in high and low bytes (big endian)
	uint8_t ByteHigh = si.i2c_read(false);
	si.i2c_stop();
	// if(Error == true) return ((ByteHigh << 8) | ByteLow); //If read succeeded, return concatonated value
	// else return -1; //Return error if read failed
	return ((ByteHigh << 8) | ByteLow); //DEBUG!
}

int ReadWord_LE(uint8_t Adr, uint8_t Command)  //Send command value, returns entire 16 bit word
{
	bool Error = SendCommand(Adr, Command);
	si.i2c_stop();
	si.i2c_start((Adr << 1) | READ);
	uint8_t ByteHigh = si.i2c_read(false);  //Read in high and low bytes (big endian)
	uint8_t ByteLow = si.i2c_read(false);
	si.i2c_stop();
	// if(Error == true) return ((ByteHigh << 8) | ByteLow); //If read succeeded, return concatonated value
	// else return -1; //Return error if read failed
	return ((ByteHigh << 8) | ByteLow); //DEBUG!
}

void SplitAndLoad(uint8_t Pos, unsigned int Val) //Write 16 bits
{
	uint8_t Len = sizeof(Val);
	for(int i = Pos; i < Pos + Len; i++) {
		Reg[i] = (Val >> (i - Pos)*8) & 0xFF; //Pullout the next byte
	}
}

void SplitAndLoad(uint8_t Pos, long Val)  //Write 32 bits
{
	uint8_t Len = sizeof(Val);
	for(int i = Pos; i < Pos + Len; i++) {
		Reg[i] = (Val >> (i - Pos)*8) & 0xFF; //Pullout the next byte
	}
}

boolean addressEvent(uint16_t address, uint8_t count)
{
	RepeatedStart = (count > 0 ? true : false);
	return true; // send ACK to master
}

void requestEvent()
{	
	//Allow for repeated start condition 
	if(RepeatedStart) {
		for(int i = 0; i < 2; i++) {
			Wire.write(Reg[RegID + i]);
		}
	}
	else {
		Wire.write(Reg[RegID]);
	}
}

void receiveEvent(int DataLen) 
{
    //Write data to appropriate location
    if(DataLen == 2){
	    //Remove while loop?? 
	    while(Wire.available() < 2); //Only option for writing would be register address, and single 8 bit value
	    uint8_t Pos = Wire.read();
	    uint8_t Val = Wire.read();
	    //Check for validity of write??
	    Reg[Pos] = Val; //Set register value
	}

	if(DataLen == 1){
		RegID = Wire.read(); //Read in the register ID to be used for subsequent read
	}
}

void stopEvent() 
{
	StopFlag = true;
	//End comunication
}

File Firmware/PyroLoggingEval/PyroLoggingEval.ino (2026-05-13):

#include "Wire.h"
#include "math.h"
#include <SPI.h>
#include <SdFat.h>
#include <MCP3421.h>
#include <DS3231_Logger.h>

#define UVA_ADR 0x02
#define UVB_ADR 0x06
#define ALS_ADR 0x0B
#define WHITE_ADR 0x0D
#define LUXMUL_ADR 0x10
#define IR_MID_ADR 0x13
#define IR_SHORT_ADR 0x15
#define THERM_ADR 0x17

#define XAXIS 0x32
#define YAXIS 0x34
#define ZAXIS 0x36

#define ADR 0x40  //Address of Pyranometer
#define ACCEL_ADR 0x1D //Address of accelerometer (ADXL343)

const uint8_t RedLED = 13;
const uint8_t GreenLED = 15;
const uint8_t BlueLED = 14;

const uint8_t BuiltInLED = 20;

const unsigned long RED = 0xFFFF0000L;
const unsigned long GREEN = 0xFF00FF00L;
const unsigned long BLUE = 0xFF0000FFL;
const unsigned long MAROON = 0xFF800000L;
const unsigned long GOLD = 0xFFFFD700L;
const unsigned long ORANGE = 0xFFFFA500L;
const unsigned long PURPLE = 0xFF800080L;
const unsigned long CYAN = 0xFF00FFFF;
const unsigned long BLACK_ALERT = 0x802019FF;
const unsigned long OFF = 0x00;

const float LuxRes = 0.0036; //Min resolution of lux measurement

const float KippAndZonenConv = 1.257e-5; // [V/W/m^2] for a given kipp and zonen pyranometer 

const float A = 0.003354016;
const float B = 0.0003074038;
const float C = 1.019153E-05;
const float D = 9.093712E-07;

////////////////////////////////////SD////////////////////////////////////////
const int SD_CS = 4;
char FileNameC[11]; //Used for file handling
char FileNameTestC[11]; //Used for file handling
boolean SD_Init = false;
const uint8_t SD_CD = 1;
SdFat SD;
byte  keep_SPCR;

////////////////////////////////////CLOCK//////////////////////////////////////
DS3231_Logger RTC;

MCP3421 adc;

String LogTimeDate = "2063/04/05 20:00:00";

const int Ext3v3Ctrl = 19; 

bool GlobalError = false;

void setup() {
	// put your setup code here, to run once:
	pinMode(Ext3v3Ctrl, OUTPUT);
  	digitalWrite(Ext3v3Ctrl, LOW); //Turn on power by default, turn off later to sleep

  	pinMode(RedLED, OUTPUT);
	pinMode(GreenLED, OUTPUT);
	pinMode(BlueLED, OUTPUT);
	pinMode(BuiltInLED, OUTPUT);
	LED_Color(OFF); //Turn off intially 

	digitalWrite(BuiltInLED, LOW); //Turn LED On

	Serial.begin(115200); 
	Serial.println("Welcome to the Sphere...");
	Wire.begin();
	RTC.Begin(); //Initalize RTC
	InitAccel();
	adc.Begin();
	adc.SetResolution(18);
	// adc.SetGain(8);
	// SD.begin(SD_CS);
	pinMode(SD_CS, OUTPUT);
	SDTest();
	InitLogFile();

	digitalWrite(BuiltInLED, HIGH); //Turn LED off
	if(GlobalError == false) LED_Color(GREEN);
	else LED_Color(RED);
	delay(2000);
	LED_Color(OFF);

}


void loop() {
  // put your main code here, to run repeatedly:
  GetTime(); //FIX!
  String Data = String(GetUVA()) + "," + String(GetUVB()) + "," + String(GetALS()) + "," + String(GetWhite()) + "," + String(GetLux()) + "," + String(GetIR_Short()) + "," + String(GetIR_Mid()) + "," + String(GetWatts()) + "," + String(GetAngle(3)) + "," + String(GetAngle(4)) + "," + LogTimeDate;
  LogStr(Data);
  Serial.println(LogTimeDate);
  delay(1000);
}

void LED_Color(unsigned long Val) {
	int Red = 0; //Red led color
	int Green = 0;  //Green led color
	int Blue = 0;  //Blue led color
	int Lum = 0;  //Luminosity

	//Parse all values from single Val
	Blue = Val & 0xFF;
	Green = (Val >> 8) & 0xFF;
	Red = (Val >> 16) & 0xFF;
	Lum = (Val >> 24) & 0xFF;
	//  Lum = 255 - Lum; //Invert since LEDs are open drain

	analogWrite(RedLED, 255 - (Red * Lum)/0xFF);
	analogWrite(GreenLED, 255 - (Green * Lum)/0xFF);
	analogWrite(BlueLED, 255 - (Blue * Lum)/0xFF);
}

void GetTime() {
	//Update global time string
	// DateTime TimeStamp = RTC.now();
	// LogTimeDate = String(TimeStamp.year()) + "/" + String(TimeStamp.month()) + "/" + String(TimeStamp.day()) + " " + String(TimeStamp.hour()) + ":" + String(TimeStamp.minute()) + ":" + String(TimeStamp.second());  
	LogTimeDate = RTC.GetTime(0);
}

float GetWatts() 
{
	float Val = adc.GetVoltage();
	Serial.println(Val, 9); //DEBUG!
	return Val/KippAndZonenConv;
}

void InitLogFile(){
    String FileName = "Pyro";
    int FileNum = 1;
    String NumString = "01";
    (FileName + "01"+ ".txt").toCharArray(FileNameC, 11);
    while(SD.exists(FileNameC)) {
      FileNum += 1;
      NumString = String(FileNum, DEC);
      (FileName + NumString + ".txt").toCharArray(FileNameC, 11);
    }
    (FileName + NumString + ".txt").toCharArray(FileNameC, 11);
  
    LogStr("UVA, UVB, ALS, White, Lux [lx], IR Short, IR Mid, KippAndZonen [W/m^2], Roll [deg], Pitch [deg], Time [UTC]"); 
}

int LogStr(String Val) {
  File DataFile = SD.open(FileNameC, FILE_WRITE);

  // if the file is available, write to it:
  if (DataFile) {
    DataFile.println(Val);
	   // return 0;
  }
  // if the file isn't open, pop up an error:
  else {
	   // return -1;
  }

  DataFile.close();
}

// uint8_t InitLibelle()
// {

// }

void SDTest() {
	bool SDError = false;
	// bool SD_Test = true;

	pinMode(SD_CD, INPUT);
	bool CardPressent = digitalRead(SD_CD);

	Serial.print("SD: ");

	if(CardPressent) Serial.println(" NO CARD");

	if (!SD.begin(SD_CS)) {
		Serial.println("SD Failed!");
		GlobalError = true;
  	}

	String FileNameTest = "HWTest";
	(FileNameTest + ".txt").toCharArray(FileNameTestC, 11);
	SD.remove(FileNameTestC); //Remove any previous files

	randomSeed(analogRead(A7)); //Seed with a random number to try to endsure randomness
	int RandVal = random(30557); //Generate a random number between 0 and 30557 (the number of words in Hamlet)
	char RandDigits[6] = {0};
	sprintf(RandDigits, "%d", RandVal); //Convert RandVal into a series of digits
	int RandLength = (int)((ceil(log10(RandVal))+1)*sizeof(char)); //Find the length of the values in the array

	File DataWrite = SD.open(FileNameTestC, FILE_WRITE);
	if(DataWrite) {
	DataWrite.println(RandVal);
	DataWrite.println("\nHe was a man. Take him for all in all.");
	DataWrite.println("I shall not look upon his like again.");
	DataWrite.println("-Hamlet, Act 1, Scene 2");
	}
	DataWrite.close();

	char TestDigits[6] = {0};
	File DataRead = SD.open(FileNameTestC, FILE_READ);
	if(DataRead) {
	DataRead.read(TestDigits, RandLength);

	for(int i = 0; i < RandLength - 1; i++){ //Test random value string
	  if(TestDigits[i] != RandDigits[i]) {
	    // SDError = true;
	    GlobalError = true;
	  }
	}
	}
	DataRead.close();

	//Print SD file info??
	//  if(!SDError && !GlobalError) {


	keep_SPCR=SPCR; 
  
	if(SDError && !CardPressent) Serial.println("FAIL");
  else Serial.println("PASS");

	//  SPI.end();
	//  digitalWrite(SD_CS, LOW);
	//  pinMode(5, OUTPUT);
	//  digitalWrite(5, LOW);
	//  pinMode(6, OUTPUT);
	//  digitalWrite(6, LOW);
	//  pinMode(7, OUTPUT);
	//  digitalWrite(7, LOW);
}

uint8_t InitAccel()  //Add variable address ability??
{
  WriteByte(ACCEL_ADR, 0x2D, 0x08); //Turn on accelerometer
  WriteByte(ACCEL_ADR, 0x31, 0x08); //
  WriteByte(ACCEL_ADR, 0x38, 0x00); //Bypass FIFO
  WriteByte(ACCEL_ADR, 0x2C, 0x0A); //Setup rate
}
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

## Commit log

2018-06-05 Rebuild repo
    Previous repo was borked due to inclusion of large peripheral files from LTSpice simulations, repo is now being rebuild with changes to gitignore in order to prevent issues like this in the future
    [Apogee_SP110_Response.csv, IR_MidWave_Response.csv, IR_ShortWave_Response.csv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]
2018-06-07 Added sub-alpha firmware
    I2C firmware used for translating I2C commands and readdressing (currently not functional), driver firmware is used as a true sensor interface to read from sub-slaves and populate registers (currentl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
2018-06-08 Improved driver files, and demo file
    Driver file in BETA, demo file still in ALPHA
2018-06-12 Updated to driver firmware and demo interface
    Initial design of driver firmware nearly completed, basics of demo interface complete, polishing and boilerplate required
2018-06-13 Firmware and demo interface updated
    Driver firmware and DysonReadDemo ready for full scale testing
2018-06-13 Added accelerometer to demo
2018-06-19 Improved firmware to include auto ranging
    Also added logging software ALPHA revision
    [ShortWaveModule_BOM.csv, ShortWaveModule_SmallBoard.brd, ShortWaveModule_SmallBoard.sch]
2018-06-27 Added pullups to shortwave module
    Added pullups to onboard I2C on shortwave module, still need to fix silk screen and update parts before ready to ship
    [ShortWaveModule_SmallBoard.brd, ShortWaveModule_SmallBoard.sch]
2018-06-28 Updated parts and BOM
    [ShortWaveModule_BOM.csv, ShortWaveModule_SmallBoard.brd, ShortWaveModule_SmallBoard.sch]
2018-06-28 Updated part info, license and BOM
    [ShortWaveModule_SmallBoard.brd]
2018-06-28 Generated gerbers for Mrk 0.1
    Added Gerbers for Mrk 0.1 revision, fixed silk screen issues, added pullup resistors for on board I2C on shortwave module, and changed amplifiers on longwave module (eliminated use of LTC2054HV, and switched to using LTC2050HV due to availability), also fixed (flipped) thermistor arraignment on shortwave module
    [ShortWaveModule_BOM.csv, ShortWaveModule_SmallBoard.brd, ShortWaveModule_SmallBoard.sch]
2018-07-10 Added mechanical parts and updated gerbers and ref designators
    Updated gerbers for long wave and fixed reference designators for short wave
    [BoardCaseMount.SLDPRT, BoardCaseMount.STL, PipeMount.DXF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]
2018-07-17 Added solder stencil DXF
    [Stencil.dxf]
2018-07-21 Added pipe mount assembly
    [PipeMount.SLDASM]
2018-11-09 Added pin descriptors for Dyson v0.1
2018-11-09 Updated SW firmware, fixed ADR issue
    Updated Dyson shortwave firmware to fix alternative ADR setting issue. Also removed some stale debug statements and changed default flag to log when power is first applied to device in order to work best with power cycle logger setup. Still want to improve sampling time.
    [Dyson_Driver_ShortWave.ino]
2018-11-09 Updated case mount to allow for pins to not clash
    added cutout to allow for clearance of backside of pins
    [BoardCaseMount.SLDPRT, BoardCaseMount.STL]
2018-11-09 Added cutouts in mount
    Added cutouts for ICSP headers to allow board to lay flat on mount
    [BoardCaseMount.SLDPRT, BoardCaseMount.STL]
2018-11-27 Added response curves for LW
    Added response curves for longwave sensor, and fitting info for thermistor on LW
2018-11-29 Added mechanical parts
    Added placement guides and drill guide
    [DiffuserGuide_BOTTOM.SLDPRT, DiffuserGuide_BOTTOM.STL, DiffuserGuide_TOP.SLDPRT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]
2018-11-29 Added mechanical designs and reg map
    Added new mechanical designs along with a preliminary register map, continued expansion to come
    [WP-31_InternalMountPlate.SLDPRT]
2018-12-01 Updated firmware
    Fixed update timing issue, need to remove digital pin debug statements!
    [Dyson_Driver_ShortWave.ino]
2018-12-06 Changed busy flag structure
    Changed the structure of the busy flag to reduce the time the system is labeled as "busy" to just the time when actual registers are being updated. Need to remove bit flip debug statements!
    [Dyson_Driver_ShortWave.ino]
2018-12-12 Added SW mount w/desiccant holders
    Added a new version of the board holder for the short wave unit, with spaces for holding desiccant that will not allow it to move around in the box and cause problems
    [BoardCaseMount_DesicantHolders.SLDPRT, BoardCaseMount_DesicantHolders.STL]
2018-12-13 Added SW mount w/desiccant holders
    [BoardCaseMount_DesicantHolders.SLDPRT, BoardCaseMount_DesicantHolders.STL]
2018-12-15 Added pipe mount cutout shape
    [PipeMount_Outline.DXF]
2019-01-14 Fixed crash in Board Mount
    The pins of the bottom header would crash with the body of the BoardCaseMount, this was fixed with an cutout in `BoardCaseMount_DesicantHolder.SLDPRT`. Also updated`.stl` and generated bulk GCode to print 4 units at once.
    [BoardCaseMount_DesicantHolders.SLDPRT, BoardCaseMount_DesicantHolders.STL]
2019-02-21 Added Kipp and Zonen test script
    Added logging script for use with Margay that measures data from Dyson SW and Kipp and Zonen CMP3. Need to fix address error
    [Dyson_KippZonen_Test.ino]
2019-05-21 Added experimental high speed/low power firmware
2019-06-24 String typing, Margay1.0, Correct I2C addr
    [Dyson_KippZonen_Test.ino]
2020-05-27 Design files
    [PyroTestingBoard.SLDPRT, PyroTestingBoard.STEP, PyroTestingBoard.STL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]
2020-05-27 Easel pipe mount
2020-05-27 Millable components and U bolt sizes
2021-11-02 Dyson-->Monarch, aside from Eagle files & co
    [StencilMount_DysonLW.SLDPRT, StencilMount_DysonLW.STL]
2021-11-03 Dyson --> Monarch in sch and on silk
    [ShortWaveModule_SmallBoard.brd, ShortWaveModule_SmallBoard.sch]
2026-05-13 Add bare board photo to README
2026-05-13 Rename Monarch→Libelle, organize repo structure
    - Rename all Monarch/Dyson references to Libelle in filenames and content
    - Move firmware sketches into Firmware/
    - Move CAD/mechanical files into Mechanical/
    - Move MATLAB analysis files and spectrum data into Analysis/
    - Move documentation text files into Documentation/
    - Rename 'Spectrum Response Plots' to Analysis/SpectrumResponsePlots (no spaces)
    [Apogee_SP110_Response.csv, BoardCaseMount.SLDPRT, BoardCaseMount.STL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]
2026-05-13 Fix supply voltage range to 3.3–5.5 V per TPS79733 datasheet
2026-05-13 Rename Monarch→Libelle in file contents
2026-05-13 Rename ShortWaveModule→Libelle in Hardware/; fix embedded project names
    Updates PROJECT attribute from Dyson/Monarch to Libelle in Eagle
    schematic files, and silk text on SmallBoard layout.
    [Libelle.brd, Libelle.sch, Libelle_BOM.csv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]
2026-05-13 Add CITATION.cff; fix embedded project names in Eagle files
    [Libelle.sch, Libelle_SmallBoard.brd, Libelle_SmallBoard.sch]
2026-05-13 Fix J1 naming conflict in README (screw terminal vs. address jumper)
2026-05-13 Correct address jumper designator to JP1 in README
    JP1 selects Libelle module I2C address; JP2 is the ADXL343
    accelerometer internal address select (firmware-managed).
2026-05-13 Document JP1 and JP2 solder jumpers in README
2026-05-13 Fix KippZonen firmware API, add .claude to .gitignore, add CNC images to README
    [Libelle_KippZonen_Test.ino]
2026-05-13 Add Hardware/DESIGN_NOTES.md; remove duplicate SpectrumPlot.m
    Documents Bobby's LDO vs. buck converter design decision (TPS62172
    explored and rejected in favour of TPS79733 due to switching noise
    sensitivity of LTC2054 TIA signal chain and low load current).
    Also documents the TIA simulations in Simulations/.
    Removes root-level Analysis/SpectrumPlot.m duplicate; canonical copy
    is in Analysis/SpectrumResponsePlots/Plotting/.
2026-05-13 Remove abandoned TPS62172 buck converter simulations
    Rationale documented in Hardware/DESIGN_NOTES.md. Files preserved
    in git history if ever needed.
    [TPS62172_TRANS.DSN]
2026-05-31 Add register map section: current layout, UVB bug, and proposed Schema 1
    Documents the existing 26-byte register map and a critical firmware/library
    mismatch: firmware writes UVB at 0x07, library reads from 0x06, causing
    getUVB() to return approximately true_UVB × 256. All historical UVB data
    is affected. Also documents the proposed NW-Device-Specification Schema 1
    layout (two pages, UVB bug corrected, grouped by sensor chip).
2026-05-31 Add proposed ADXL343 bridging to Schema 1 Page 1 Block 3; reference issue #19
    Documents that hardware v2 will move the ADXL343 from the master I2C bus
    to the ATtiny software I2C bus, enabling a single-address register map.
    Block 3 of Page 1 is reserved for accelerometer X/Y/Z (int16 each).
2026-06-01 README: add NW-Device-Specification Schema 1 Page 0 block
    Documents the device's 32-byte EEPROM identity block per
    https://github.com/NorthernWidget/NW-Device-Specification
2026-06-01 Page 1 status byte: add pan-fault (bit 7), label 0x27 as extended fault byte; clarify status bit migration
    Reflects the NW-Device-Specification Schema 1 standard: bit 7 is the
    pan-fault summary; 0x27 is the reserved extended fault byte.
    Also clarifies open item 1: the status bit migration requires both a
    register address change (0x00 → 0x20) and a bit position change (7 → 0);
    they must happen together.
2026-06-01 Move extended fault byte to 0x21; sensor data starts at 0x22

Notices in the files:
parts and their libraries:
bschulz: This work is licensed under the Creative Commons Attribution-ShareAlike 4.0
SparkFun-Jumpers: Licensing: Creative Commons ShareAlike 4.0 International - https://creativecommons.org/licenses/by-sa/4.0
